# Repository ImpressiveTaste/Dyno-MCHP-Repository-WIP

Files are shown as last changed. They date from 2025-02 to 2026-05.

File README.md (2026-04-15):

# MC-Dyno: Motor Control Dynamometer  

<p align="center">
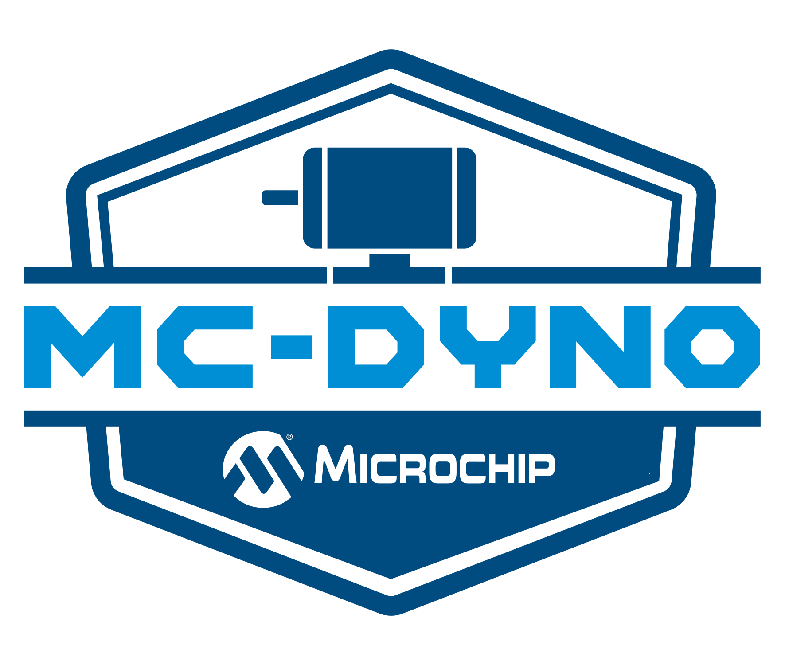
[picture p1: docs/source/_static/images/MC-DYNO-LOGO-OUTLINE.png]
MC-DYNO Logo
  
</p>

Last updated: December 2025

MC-Dyno is a compact, X2C-enabled motor dynamometer designed for load testing, algorithm validation, sensorless control development, and AI/ML data capture.  
This repository documents the setup, firmware workflow, load profiles, and usage instructions for running the MC-Dyno on Microchip motor-control platforms.

Documentation website (HTML build): [https://impressivetaste.github.io/Dyno-MCHP-Repository-WIP/](https://impressivetaste.github.io/Dyno-MCHP-Repository-WIP/)

The system supports both standalone operation (HEX-only, no toolchain required) and full SCILAB/X2C model-based workflow that allows to set torque and behaviour directly clicking on the model designed through model based design.  

It is compatible with the following hardware platforms:

- [MCLV-2](https://www.microchip.com/en-us/development-tool/dm330021-2)  
- [MCLV-48V-300W](https://www.microchip.com/en-us/development-tool/ev18h47a)  
- [MCHV-3](https://www.microchip.com/en-us/development-tool/dm330023-3)  
- [MCHV-230V-1.5kW](https://www.microchip.com/en-us/development-tool/ev78u65a)
---

<p align="center">
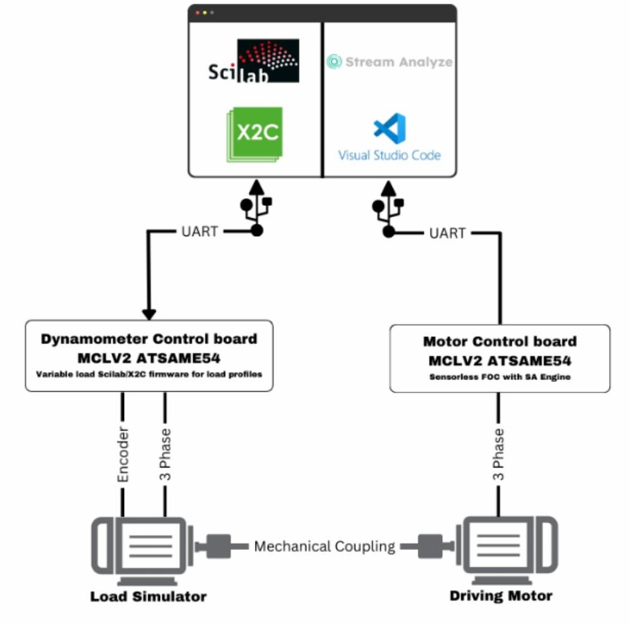
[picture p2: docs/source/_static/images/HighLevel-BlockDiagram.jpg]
High-Level-Block-Diagram
  
</p>

## What MC-Dyno Is

A ready-to-use motor dyno environment supporting:

- 4Q operation (CW/CCW, motor/generator/brake)
- Programmable load profiles (constant, trapezoid, sine, fan, angle-dependent, table-driven)
- Motor torque/speed profiles for DUT evaluation
- AI/ML dataset creation (anomalies, noise patterns, dynamic behaviours)
- Real-time monitoring via X2C Scope
- Standalone operation without Scilab/X2C if desired

The goal is to allow anyone to test motor algorithms quickly, without building or buying a custom, often expensive, setup.

## Key Features

### DYNO Mode
- Constant load (potentiometer or numeric)  
- Trapezoidal load (frequency, high/low values, ramp rates)  
- Fan load (k · n²)  
- Sine load (frequency, amplitude, offset)  
- Angle-dependent loads (electrical / mechanical)  
- Table-driven load profiles:
  - Unbalanced load (constant + sine)
  - Broken bearing (constant + rectangle)
  - Triangle (constant + triangle)
- Compressor-like load profiles (supported via table definition)

### Motor Mode
- Constant torque  
- Constant speed  
- Potentiometer or variable setpoints  
- Trapezoidal speed profiles  

### Hardware Highlights
- MCLV-2 motor control board  
- ATSAME54 PIM  
- Hurst 300 motor with encoder  
- RS232 connection (X2C Scope compatible)
- Optional Magtrol TS105/011 torque sensor  
- 3D-printable universal bracket (OpenSCAD)

## Repository Layout

```
miniDyno-2.0/
├── README.md <-- you are here
├── 3Dparts/ <-- OpenSCAD + STL universal motor bracket
├── MCDyno/
│ ├── mc_foc_dyno_same54_mclv2/
│ │ └── doc/ <-- project docs + standalone assets
│ └── ...
├── docs/ <-- rendered docs + static assets
└── ...
```

## Project Naming Conventions

Project names use underscore-separated "placeholder" in a fixed order:
`<topic>_<algorithm>_<S/SL>_<datatype>_<device>_<feature>_<demo-board>_<customer>`

The projects only keeps the "placeholders" that apply.

"placeholder" options (from the motor control naming list):
- topic (project area): MC, BLINKY, PWR, SENS
- algorithm (control/app type): FOC, BLOCK, MB, H3, QSPIN, LEG
- S/SL (variant tag): S, SL, SSL, DYNO, ZSMT, ZSMTLF
- datatype (numeric format): FIP, FLOAT, DOUBLE, FIP32
- device (target MCU): dsPIC33CK, dSPIC33EP, dSPIC33A, SAME54, SAME70, dsPIC33CKMC, dsPIC33CD, SAMC21, SAMD21
- feature (optional flag): PLL, SMO, PFC
- demo board (target board): MCLV2, MCHV2, MCHV3, MCLV48V300W, MCHV230VAC1.5KW, LVMC
- customer (optional tag): SA

"Placeholder" meanings and links:
- topic: MC = Motor Control; BLINKY = easy blinky example; PWR = Digital Power; SENS = sensing demonstration.
- algorithm: FOC = Field Oriented Control; BLOCK = Block commutation (six-step commutation); MB = motorBench-generated code; H3 = MPLAB Harmony 3 generated code; QSPIN = MPLAB Harmony QuickSpin generated code; LEG = Legacy (hand-authored) code.
- S/SL: S = sensored; SL = sensorless; SSL = sensorless single-shunt; DYNO = dynamometer (dyno) project; ZSMT = Zero-Speed/Maximum-Torque (ZS/MT) algorithm ([Microchip ZSMT overview](https://www.microchip.com/en-us/tools-resources/configure/mplab-harmony/quickspin/zsmt-algorithm)); ZSMTLF = ZS/MT low-frequency variant.
- datatype: FIP = fixed-point (usually 16-bit); FIP32 = 32-bit fixed-point; FLOAT = floating-point; DOUBLE = double-precision floating-point.
- feature: PLL = Phase-Locked Loop ([AN1292](https://ww1.microchip.com/downloads/en/AppNotes/01292A.pdf)); SMO = Sliding Mode Observer ([AN4398](https://ww1.microchip.com/downloads/aemDocuments/documents/MCU32/ApplicationNotes/ApplicationNotes/Sensorless-Field-Oriented-Control-for-a-Permanent-Magnet-Synchrono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)); PFC = Power Factor Correction([AN1208](https://ww1.microchip.com/downloads/en/appnotes/01208a.pdf)).
- demo board: [MCLV2](https://www.microchip.com/en-us/development-tool/dm330021-2), [MCHV2](https://www.microchip.com/en-us/tools-resources/reference-designs/aircon-board), [MCHV3](https://www.microchip.com/en-us/development-tool/dm330023-3), [MCLV48V300W](https://www.microchip.com/en-us/development-tool/ev18h47a), [MCHV230VAC1.5KW](https://www.microchip.com/en-us/development-tool/ev78u65a), [LVMC](https://www.microchip.com/en-us/solutions/technologies/motor-control-and-drive/hardware-development-tools).
- Partner: SA = Stream Analyze (AI/data collection)([Documentation](https://studio.streamanalyze.com/docs/guides/general-guides/intro)).

Examples:
- `mc_foc_dyno_same54_mclv2` (MC + FOC + DYNO + SAME54 + MCLV2)
- `mc_mb_sl_fip_dsPIC33CK_mclv48v300w.X` (MC + MB + SL + FIP + dsPIC33CK + MCLV48V300W)
- `MC_FOC_DYNO_SAME54_MCLV2.X.production.hex` (same fields, exported artifact)

## Requirements

### Hardware
- MCLV-2 development board  
- ATSAME54 PIM  
- Hurst 300 motor (with QEI encoder)  
- RS232 cable (DYNO ↔ Motor board)  
- Optional: Magtrol torque sensor  

### Jumpers
- JP1, JP2, JP3 → Current sense  
- JP4, JP5 → UART  
- Motor phases:
  - M1 = red
  - M2 = white
  - M3 = black
- Encoder:
  - HA = QEI white
  - HB = QEI blue

**Important:**  
Ensure the DYNO board power is physically connected to the motor board.  
Generator mode requires a valid power path to dissipate energy.

## Standalone Usage (No Scilab / No X2C)

### What you need
- Microchip programmer (ICD4, PICkit4, SNAP)
- MPLAB X or IPE

### Steps
1. Navigate to `MCDyno/mc_foc_dyno_same54_mclv2/doc/standalone` in the Github project.
2. Program the file:  
   **MC_FOC_DYNO_SAME54_MCLV2.X.production.hex**
3. Disconnect programmer and reset the MCLV-2.
4. Run **start.bat**.
5. In the GUI:
   - Select your COM port  
   - Press **Connect**  
   - Switch to the **Model** tab  

You're now running MC-Dyno in standalone mode.

Optional IGaT display (EV14C17A): program the display HEX separately from
`MCDyno/igat_ev14c17a/doc/standalone/`.

Motor-side DIM firmware (MCLV-48V-300W): program one of the DIM HEX files from
`motor_ACT57BLF02/mclv48v300w_dim_hex/doc/standalone/` to showcase different
algorithms (Single-Shunt, ZS/MT, or X2C-enabled).

## Using miniDyno with SCILAB + X2C

### Requirements
- Scilab 6.1.1  
- X2C 6.4  
- MPLAB X (Harmony 3 + XC32 free compiler)  
- Microchip programmer  

This mode allows you to modify model parameters, load tables, and control algorithms using X2C’s model-based workflow.

## DYNO Torque Profiles

### torque_mode
- 0 = Constant (potentiometer)
- 1 = Constant (const_torque)
- 2 = Trapezoid (freq, high, low, Tr, Tf)
- 3 = Fan load (fan_gain)
- 4 = Sine (A, f, fmax, Offset)
- 5 = Unbalanced (GainT5, ConstT5)
- 6 = Broken bearing (GainT6, ConstT6)
- 7 = Triangle (GainT7, ConstT7)

## Motor Mode Parameters

#### speed_mode
- 0 = Constant speed (potentiometer)
- 1 = Constant speed (const_speed)
- 2 = Trapezoidal speed profile

### Additional controls:

#### motor_torquemode
- 1 = speed control
- 0 = torque control

#### DynoMotor
- 1 = Dyno mode
- 0 = Motor mode

## X2C Scope

1. Start X2C Scope  
2. Select COM port  
3. Set Sample Time Factor  
4. Press **Sample**  

Signals stream in real time for debugging load/torque profiles, speed control, angle behaviour, and anomalies.

## 3D Printable Brackets

For making the MC-Dyno, there is a need of brakets to fix the motors, and allow for the connection between the rotor shafts guaranteeing alignment. To do so, in the location: `3Dparts` of this repository, both STL and openSCAD 3D models are made avaialble to allow to use standard brakets for some specific motors. 

If you are using a different motor, you can use the [openSCAD](https://openscad.org) files to create your own motor braket parametrically. If you make a new motor, feel free to share in this repository. 

Printing recommendations in a standard FDM printer:
- PLA or PETG (PETG preferrable)  
- 0.2 mm layer height  
- 100% infill  

## Future Enhancements

- Position control for ZSMT tuning  
- Standalone GUI  
- Torque sensor calibration  
- Real torque control mode  
- Power measurement (in/out)  
- MCHV-2/3 support  
- MCLV-48V-300W port  

## Want to contribute?
This project is open source and contributions are welcome. 
If you are new to GitHub, Github pages, and so on... don't worry, here is a small video that tries to explain how to get a setup for contributions ready: https://youtu.be/irQH9ktzQAw

## Official Logos

The MC-Dyno logos are available for use in documentation, presentations, and related projects. The following variants are provided:

| Logo | File | Best for |
|---|---|---|
|  | `MC-DYNO-LOGO-OUTLINE.png` | Light backgrounds |
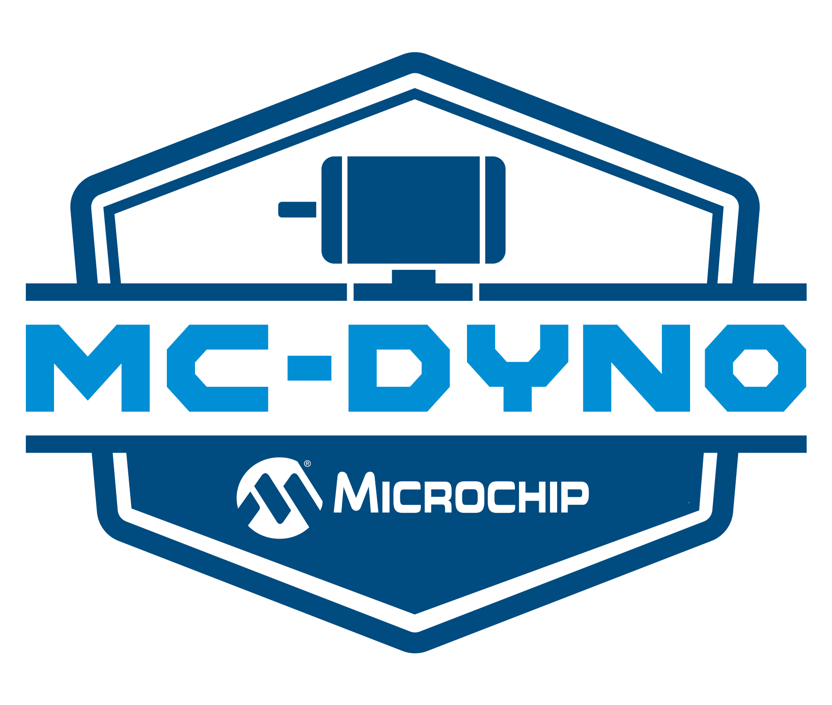
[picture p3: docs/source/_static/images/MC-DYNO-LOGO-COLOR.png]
|  | `MC-DYNO-LOGO-COLOR.png` | General use |
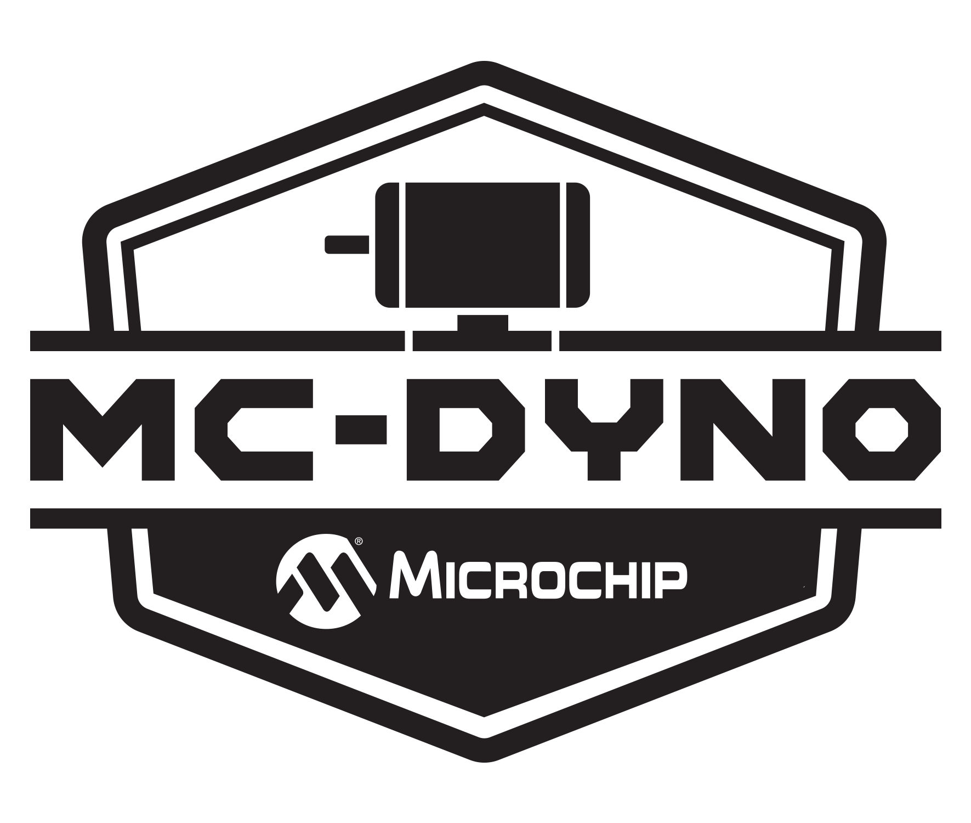
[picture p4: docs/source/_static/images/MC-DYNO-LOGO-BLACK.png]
|  | `MC-DYNO-LOGO-BLACK.png` | Print / monochrome |
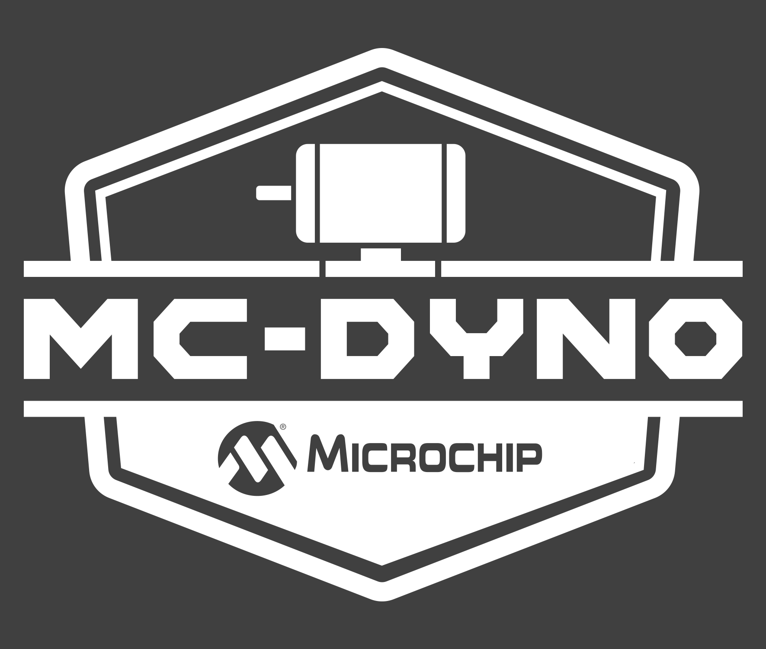
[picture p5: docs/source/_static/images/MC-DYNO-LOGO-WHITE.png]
|  | `MC-DYNO-LOGO-WHITE.png` | Dark backgrounds |

All logos are located in `docs/source/_static/images/`.

----------------------------------------------------------------------
REFERENCE & DISCLAIMER
----------------------------------------------------------------------

This project, including all hardware designs, documentation, images, and configuration examples, is provided for reference and evaluation purposes only.

It is supplied “AS IS”, without any express, implied, or statutory warranties, including but not limited to warranties of merchantability, fitness for a particular purpose, or non-infringement. The information is intended to assist with experimentation, learning, and prototyping and does not constitute a certified or production-ready design.

The author assumes no responsibility or liability for any errors, omissions, hardware damage, data loss, personal injury, or other consequences arising from the use, reproduction, modification, or deployment of this material. Users are solely responsible for verifying correctness, safety, electrical compliance, and suitability for their specific application

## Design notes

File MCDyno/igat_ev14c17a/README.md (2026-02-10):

# IGaT Display (EV14C17A) Firmware

This folder is for the Integrated Graphics and Touch (IGaT) Curiosity Evaluation Kit
(EV14C17A) display firmware used alongside the Dyno. The IGaT board is separate
hardware from the dyno controller and is programmed independently.

The IGaT display HEX file is in "MCDyno/igat_ev14c17a/doc/standalone/ATSAME51J20A_MC_Dyno_08_01_2026_IGAT.hex"

Currently the IGAT is only used as a display, but feel free to modify the code, such to be able to use it as a controller for the Dyno or motor.

## Programming (Standalone)

1. Connect directly with a microUSB cable to the debug port of the EV14C17A board.
2. In MPLAB IPE, select the ATSAME51PJ20A device on the kit.
3. Program the HEX from `doc/standalone/`.
4. Reset the board to run the UI.

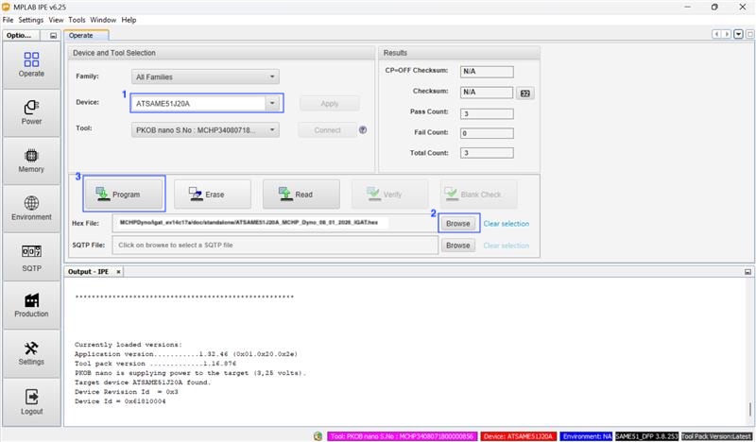
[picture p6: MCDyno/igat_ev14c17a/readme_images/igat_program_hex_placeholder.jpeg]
Programming the IGaT HEX


## Final Result

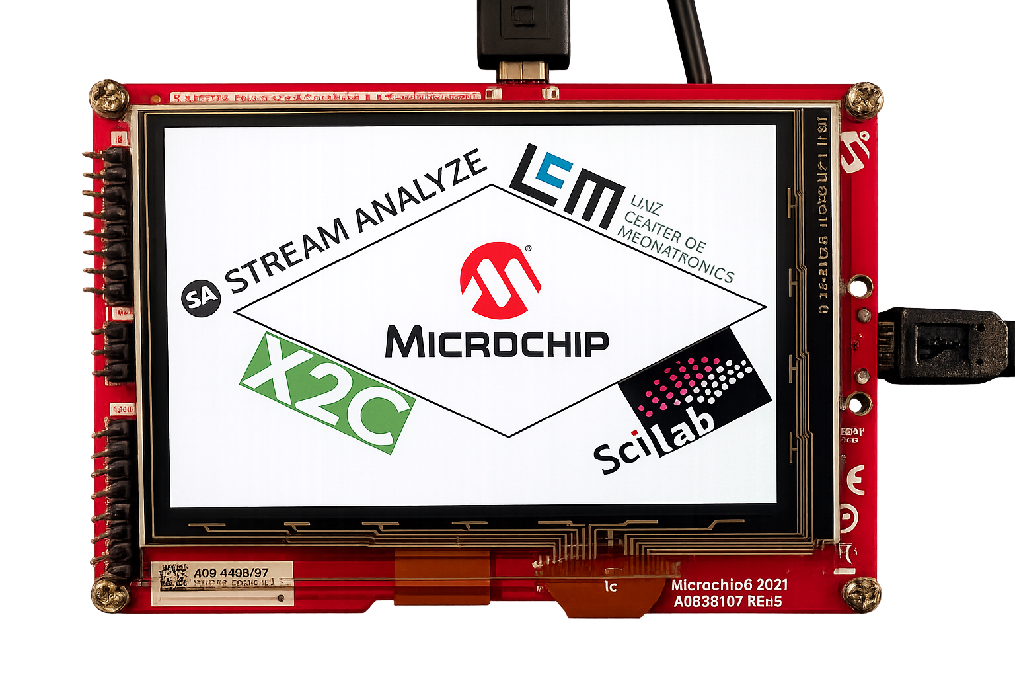
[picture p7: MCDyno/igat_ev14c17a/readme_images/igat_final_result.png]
IGaT display final result


The logos represent the different tools used for making the MC-Dyno. 

More info on the kit: https://www.microchip.com/en-us/development-tool/ev14c17a

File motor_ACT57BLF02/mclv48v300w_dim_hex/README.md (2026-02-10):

# MCLV-48V-300W Motor DIM HEX Files

These HEX files are for the motor-side control DIM plugged into the
MCLV-48V-300W Development Board (EV18H47A). Use them to showcase different
control algorithms on the dyno.

Example DIM: dsPIC33CK256MP508 Motor Control DIM (EV62P66A)
https://www.microchip.com/en-us/development-tool/ev62p66a

HEX location:

`doc/standalone/`

## Included Firmware

- `dsPIC33AK128MC106_MC_Dyno_08_01_2026_SingleShunt_DIM.hex`
  - Target DIM: dsPIC33AK128MC106.
  - MCAF R8 single-shunt current measurement demo.
  - Uses DC-link shunt reconstruction with two samples per PWM period.
  - Requires a dedicated, high-priority ADC ISR that triggers twice per PWM
    cycle and a minimum switching-state window (t_sample + dead time).
  - For estimators other than ZS/MT, use single update in Dual Edge Center
    Aligned PWM mode.

- `dsPIC33CK256MP508_MC_Dyno_08_01_2026_ZSMT_DIM.hex`
  - Target DIM: dsPIC33CK256MP508.
  - Zero-Speed / Maximum Torque (ZS/MT) Estimator
  - ZS/MT is a sensorless position and speed estimation algorithm specifically
    designed to operate where back-EMF based estimators fail, at zero and
    ultra-low speeds.
  - Operating Principle - High-Frequency Signal Injection:
    ZS/MT injects a high-frequency excitation voltage into the stator and
    measures the motor response to determine rotor angle at standstill.
  - Motor Requirements (Saliency):
    Requires significant Ld != Lq saliency, intended for IPMSM machines.
  - Startup Sequence - IPC for Zero-Speed Torque Production:
    Uses "ZS/MT + Initial Position Correction (IPC)" to align the stator field
    before motion begins.
  - Hybrid Operation - Low-Speed to High-Speed Transition:
    Uses ZS/MT at low speed and a back-EMF estimator (for example, PLL) at
    higher speed due to voltage headroom limits.
  - Tuning and Configuration Parameters

- `dsPIC33CK256MP508_MC_Dyno_08_01_2026_X2C_DIM.hex`
  - Target DIM: dsPIC33CK256MP508.
  - X2C-enabled variant for real-time monitoring and tuning.

## Programming (Standalone)

1. Insert the motor control DIM into the MCLV-48V-300W board.
2. Connect a programmer (ICD4, PICkit 4, SNAP).
3. In MPLAB IPE or MPLAB X, select the DIM device and program the HEX from
   `doc/standalone/`.
4. Reset the board.

Reference hardware:
https://www.microchip.com/en-us/development-tool/ev18h47a

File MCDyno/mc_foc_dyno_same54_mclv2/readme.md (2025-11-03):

# MPLAB X Project: MC_FOC_DYNO_SAME54_MCLV2

This is a dynamometer control demo project for [MCLV2 board](https://www.microchip.com/developmenttools/ProductDetails/dm330021-2) development board and [SAME54](https://www.microchip.com/DevelopmentTools/ProductDetails/PartNO/MA320207) microcontroller.

Apply dynamic load to test motor control development.

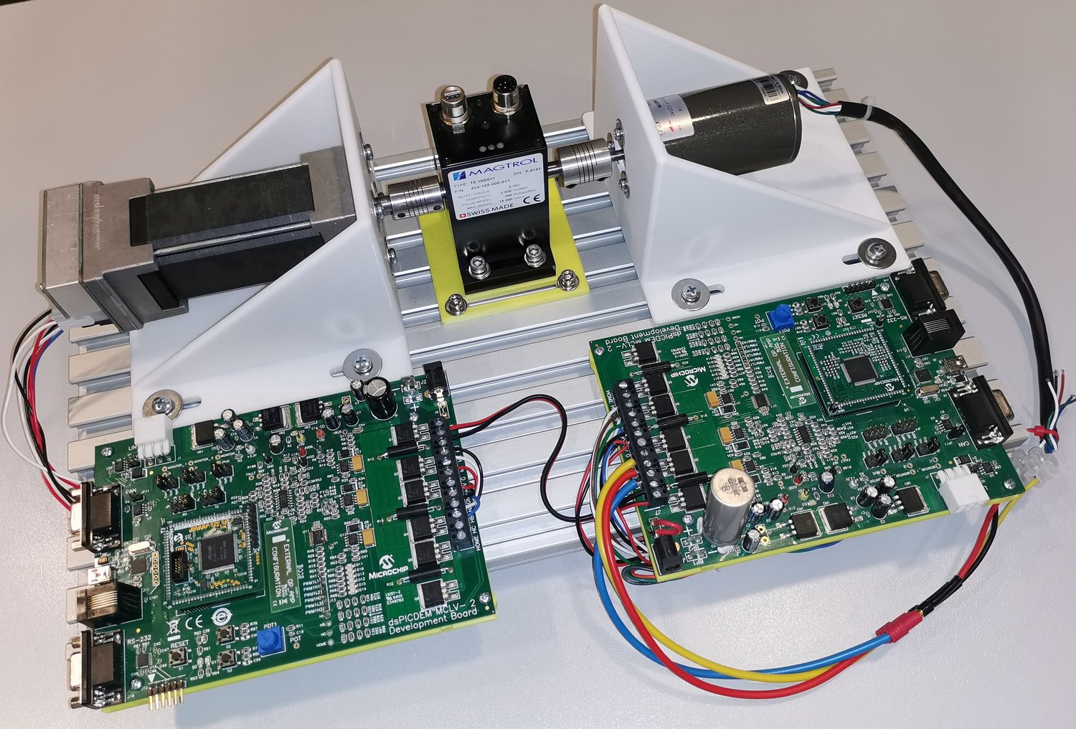
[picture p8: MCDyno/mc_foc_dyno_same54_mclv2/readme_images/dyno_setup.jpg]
Overview

### Features
* Running standalone without scilab (No SCILAB, X2C and XC32 compiler required)
* Run-time [monitoring](#monitoring-signals) (virtual scope)
* Change load profiles in run-time
  * Constant load from potentiometer
  * Constant load from variable
  * Trapezoidal load (variables: frequency, raising/falling ramp, high/low value)
  * Fan load (k*n²[rpm], variable:k 
  * Sine load ( variable: frequency, amplitude, offset)
  * Angle dependent loads ( electrical/mechanical)
    * 3 different table dependent load profiles (variables: amplitude and offset)
      * Unbalanced load (constant + sine)
      * Broken bearing (constant + rectangle)
      * Triangle ( constant + triangle)
    * Various compressor load profiles possible

## Getting Started

The demo is ready to use with the [listed hardwares below](#hardware).

1. Clone or Download project to mc_foc_sl_fip_dspic33ck_lvmc.x folder. (Keep the folder name)
2. [Connect Hardware](#connectors-used)
3. Move to [..\mc_foc_dyno_same54_mclv2\doc\standalone]
4. Program [MC_FOC_DYNO_SAME54_MCLV2.X.production.hex] onto your SAME54 PIM
5. Disconnect the programmer and reset the MCLV-2 board
6. Execute start.bat 

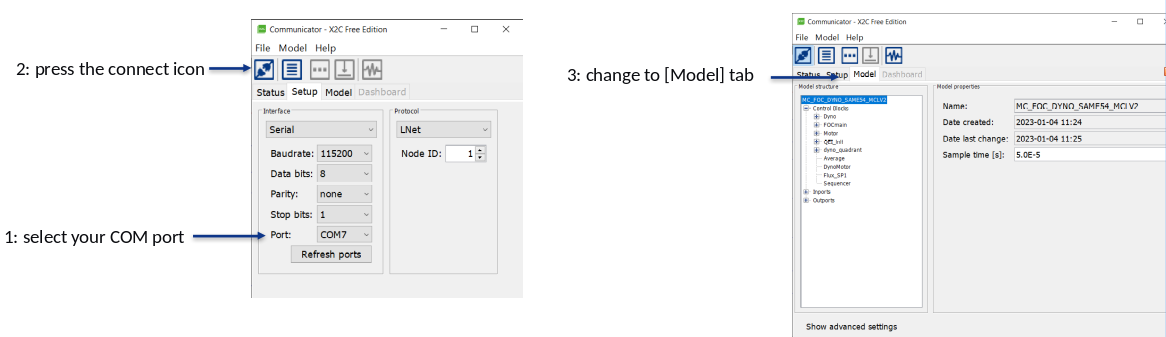
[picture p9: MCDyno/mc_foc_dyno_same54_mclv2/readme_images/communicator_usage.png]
communicator


## HW setup

* MCLV-2
* ATSAME54
* Hurst300 motor with encoder
* RS232 cable
* Software setup
* Microchip programmer (SW and HW)
* MCLV-2 Settings
  * JP1,2,3 -> Curr
  * JP4,5 -> UART
  * M1 – red
  * M2 – white
  * M3 – black
  * HA – QEI white
  * HB – QEI blue

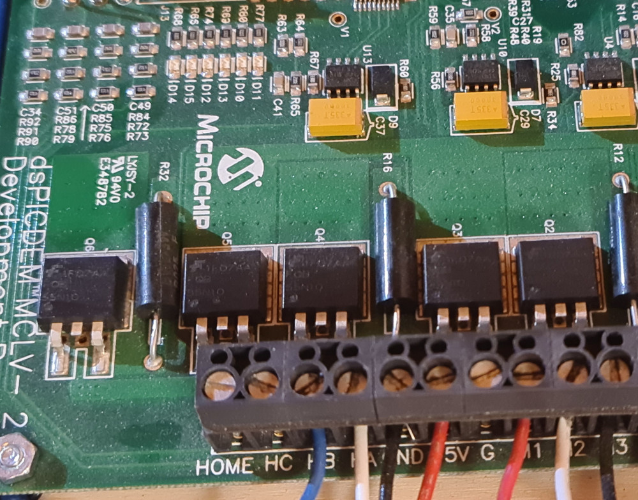
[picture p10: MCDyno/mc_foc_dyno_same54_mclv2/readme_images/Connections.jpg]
HW setup


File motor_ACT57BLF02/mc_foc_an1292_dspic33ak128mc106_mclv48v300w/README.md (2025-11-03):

 
## Sensorless FOC using PLL Estimator for PMSM : MCLV-48V-300W and dsPIC33AK128MC106 Motor Control DIM

## 1. INTRODUCTION
This document describes the setup requirements for driving a Permanent Magnet Synchronous Motor (PMSM) using Sensorless Field Oriented Control (FOC) and PLL Estimator Algorithm on the hardware platform [EV18H47A](https://www.microchip.com/en-us/development-tool/ev18h47a) "MCLV-48V-300W Development Board"  and [EV68M17A](https://www.microchip.com/en-us/development-tool/ev68m17a) "dsPIC33AK128MC106 Motor Control Dual In-line Module (DIM)".

For details about PLL estimator, refer to Microchip application note [AN1292](https://ww1.microchip.com/downloads/aemDocuments/documents/OTH/ApplicationNotes/ApplicationNotes/01292A.pdf) “Sensorless Field Oriented Control (FOC) for a Permanent Magnet Synchronous Motor (PMSM) Using a PLL Estimator and Field Weakening (FW)”
</br>

## 2. SUGGESTED DEMONSTRATION REQUIREMENTS

### 2.1 Motor Control Application Firmware Required for the Demonstration

To clone or download this application firmware on GitHub, 
- Navigate to the [main page of this repository](https://github.com/microchip-pic-avr-solutions/mclv48v300w-33ak128mc106-pmsm-an1292-foc-pll) and 
- On the tab **<> Code**, above the list of files in the right-hand corner, click Code, then from the menu, click **Download ZIP** or copy the repository URL to **clone.**
> **Note:** </br>
>In this document, hereinafter this firmware package is referred as **firmware.**
### 2.2 Software Tools Used for Testing the firmware

- MPLAB® X IDE **v6.20** 
- Device Family Pack (DFP): **dsPIC33AK-MC_DFP v1.0.33**
- Curiosity/Starter Kits Tool Pack : **PKOB4_TP v1.14.1168**
- MPLAB® XC-DSC Compiler **v3.10**
- MPLAB® X IDE Plugin: **X2C-Scope v1.6.6** 
> **Note:** </br>
>The software used for testing the firmware prior to release is listed above. It is recommended to use these or later versions of the tool for building the firmware. All previous versions of Device Family Packs (DFP) and Tool Packs can be downloaded from [Microchip Packs Repository.](https://packs.download.microchip.com/)
### 2.3 Hardware Tools Required for the Demonstration
- MCLV-48V-300W Development Board [(EV18H47A)](https://www.microchip.com/en-us/development-tool/ev18h47a)
- dsPIC33AK128MC106 Motor Control Dual In-line Module [(EV68M17A)](https://www.microchip.com/en-us/development-tool/ev68m17a)
- 24V Power Supply [(AC002013)](https://www.microchipdirect.com/dev-tools/AC002013)
- 24V 3-Phase Brushless DC Motor - Hurst DMA0204024B101 [(AC300022)](https://www.microchip.com/en-us/development-tool/AC300022) or,
- 24V 3-Phase Brushless DC Motor - Hurst DMB0224C10002 [(AC300020)](https://www.microchip.com/en-us/development-tool/AC300020)

> **Note:** </br>
> All items listed under the section Hardware Tools Required for the Demonstration are available at [microchip DIRECT](https://www.microchipdirect.com/) 
>- Hurst DMA0204024B101(AC300022) is referred as Hurst300 or Long Hurst in the firmware
>- Hurst DMB0224C10002(AC300020) is referred as Hurst075 or Short Hurst in the firmware
</br>

## 3. HARDWARE SETUP
This section describes the hardware setup required for the demonstration.
> **Note:** </br>
>In this document, hereinafter the MCLV-48V-300W Development Board is referred as **development board**.

1. Motor currents are amplified on the MCLV-48V-300W development board; it can also be amplified by the amplifiers internal to the dsPIC33AK128MC106 on the DIM. The firmware and DIM are configured to sample and convert internal amplifier outputs (**'internal op-amp configuration'**) by default to measure the motor currents needed to implement FOC. **Table-1** summarizes the resistors to be populated and removed to convert the DIM from **‘internal op-amp configuration’** to **‘external op-amp configuration’** or vice versa.

     <p align="left" >
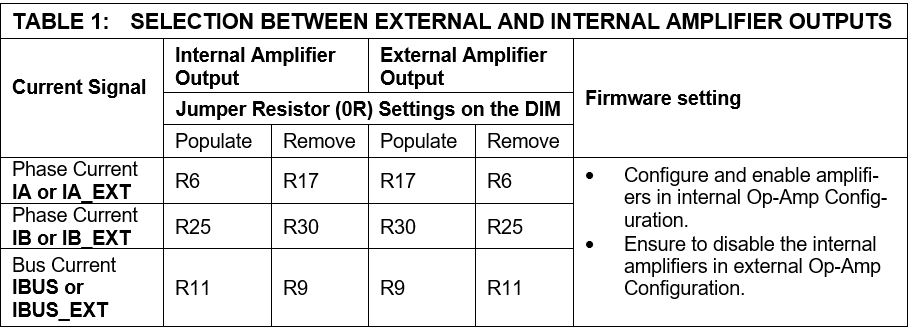
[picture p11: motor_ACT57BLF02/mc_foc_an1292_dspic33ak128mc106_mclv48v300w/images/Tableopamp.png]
     </p>

2. Insert the **dsPIC33AK128MC106 Motor Control DIM** into the DIM Interface **connector J8** on the development board. Make sure the DIM is placed correctly and oriented before going ahead.

     <p align="left" >
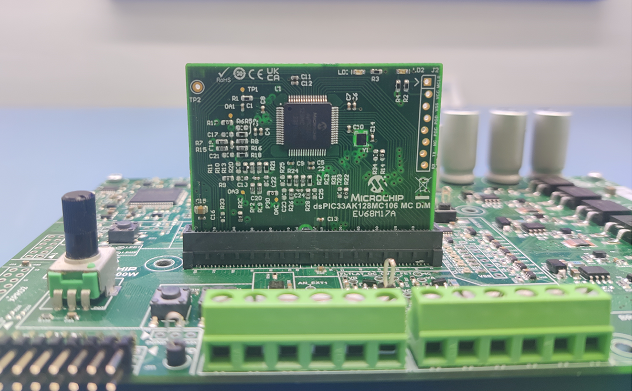
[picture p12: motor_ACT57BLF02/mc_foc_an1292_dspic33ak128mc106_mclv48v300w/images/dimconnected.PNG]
     </p>

3. Connect the 3-phase wires from the motor to PHC, PHB, and PHA of the **connector J4**(no specific order), provided on the development board.

     <p align="left" >
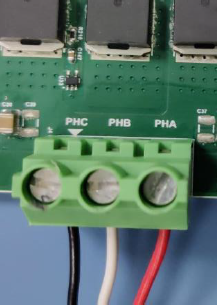
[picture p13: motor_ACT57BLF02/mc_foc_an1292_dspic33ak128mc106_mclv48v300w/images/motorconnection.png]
      </p>

4. Plug the 24V power supply to **connector J1** on the development board. Alternatively, the development board can also be powered through connector J3.
      <p align="left">
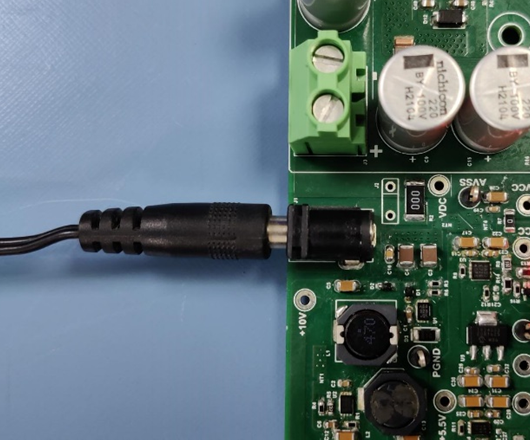
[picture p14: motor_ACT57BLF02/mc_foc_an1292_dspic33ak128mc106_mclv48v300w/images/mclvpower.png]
      </p>

 5. The board has an onboard programmer **PICkit™ On Board (PKoBv4)** , which can be used for programming or debugging the microcontroller or dsPIC DSC on the DIM. To use the onboard programmer, connect a micro-USB cable between the Host PC and **connector J16** on the development board.
      <p align="left">
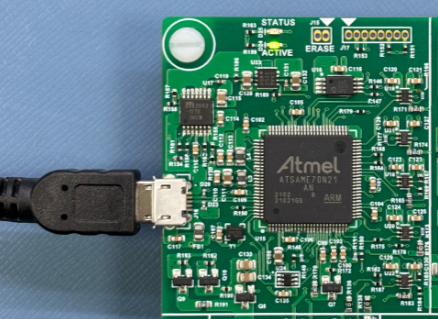
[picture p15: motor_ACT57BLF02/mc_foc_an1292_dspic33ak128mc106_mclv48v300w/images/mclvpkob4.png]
     </p>

 6. Alternatively, connect the Microchip programmer/debugger MPLAB® PICkit™ 4 In-Circuit Debugger[(PG164140)](https://www.microchip.com/en-us/development-tool/pg164140) between the Host PC used for programming the device and the **ICSP header J9** on the development board (as shown). Ensure that PICkit 4 is oriented correctly before proceeding.
      <p align="left">
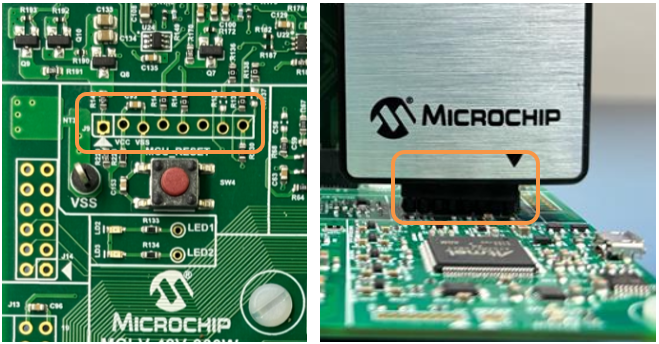
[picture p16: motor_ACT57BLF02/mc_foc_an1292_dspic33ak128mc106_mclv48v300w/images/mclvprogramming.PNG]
       </p>
 </br>

## 4. SOFTWARE SETUP AND RUN
### 4.1 Setup: MPLAB X IDE and MPLAB XC-DSC Compiler
Install **MPLAB X IDE** and **MPLAB XC-DSC Compiler** versions that support the device **dsPIC33AK128MC106** and **PKoBv4.** The MPLAB X IDE, MPLAB XC-DSC Compiler, and X2C-Scope plug-in used for testing the firmware are mentioned in the [Motor Control Application Firmware Required for the Demonstration](#21-motor-control-application-firmware-required-for-the-demonstration) section. 

To get help on  

- MPLAB X IDE installation, refer [link](https://microchipdeveloper.com/mplabx:installation)
- MPLAB XC-DSC Compiler installation steps, refer [link](https://developerhelp.microchip.com/xwiki/bin/view/software-tools/xc-dsc/install/)

If MPLAB IDE v8 or earlier is already installed on your computer, then run the MPLAB driver switcher (Installed when MPLAB®X IDE is installed) to switch from MPLAB IDE v8 drivers to MPLAB X IDE drivers. If you have Windows 8 or 10, you must run the MPLAB driver switcher in **Administrator Mode**. To run the Device Driver Switcher GUI application as administrator, right-click on the executable (or desktop icon) and select **Run as Administrator**. For more details, refer to the MPLAB X IDE help topic **“Before You Begin: Install the USB Device Drivers (For Hardware Tools): USB Driver Installation for Windows Operating Systems.”**

### 4.2 Setup: X2C-SCOPE
X2C-Scope is a MPLAB X IDE plugin that allows developers to interact with an application while it runs. X2C-Scope enables you to read, write, and plot global variables (for motor control) in real-time. It communicates with the target using the UART. To use X2C-Scope, the plugin must be installed. To set up and use X2C-Scope, refer to the instructions provided on the [web page](https://x2cscope.github.io/docs/MPLABX_Plugin.html).

## 5.  BASIC DEMONSTRATION
### 5.1 Firmware Description
The firmware version needed for the demonstration is mentioned in the section [Motor Control Application Firmware Required for the Demonstration](#21-motor-control-application-firmware-required-for-the-demonstration) section. This firmware is implemented to work on Microchip’s Digital signal controller (dsPIC® DSC) **dsPIC33AK128MC106**. For more information, see the **dsPIC33AK128MC106 Family datasheet [(DS70005539)](https://ww1.microchip.com/downloads/aemDocuments/documents/MCU16/ProductDocuments/DataSheets/dsPIC33AK128MC106-Family-Data-Sheet-DS70005539.pdf)**.

The Motor Control Demo application uses a push button to start or stop the motor and a potentiometer to vary the speed of the motor. This Motor Control Demo Application configures and uses peripherals like PWM, ADC, UART, etc. For more details, refer to Microchip Application note **[AN1292](https://ww1.microchip.com/downloads/aemDocuments/documents/OTH/ApplicationNotes/ApplicationNotes/01292A.pdf), “Sensorless Field Oriented Control (FOC) for a Permanent Magnet Synchronous Motor (PMSM) Using a PLL Estimator and Field Weakening (FW)”** available on the [Microchip website](https://www.microchip.com/en-us/application-notes).

> **Note:**</br>
> The project may not build correctly in Windows OS if the Maximum path length of any source file in the project is more than 260 characters. In case the absolute path exceeds or nears the maximum length, do any (or both) of the following:
> - Shorten the directory name containing the firmware used in this demonstration. If you renamed the directory, consider the new name while reading the instructions provided in the upcoming sections of the document.
> - Place firmware in a location such that the total path length of each file included in the projects does not exceed the Maximum Path length specified. </br>
> Refer to MPLAB X IDE help topic **“Path, File, and Folder Name Restrictions”** for details. 

### 5.2 Basic Demonstration
Follow the below instructions, step by step, to set up and run the motor control demo application:

1. Start **MPLAB X IDE** and open the project **pmsm.X (File > Open Project)** with device selection **dsPIC33AK128MC106.**  
    <p align="left">
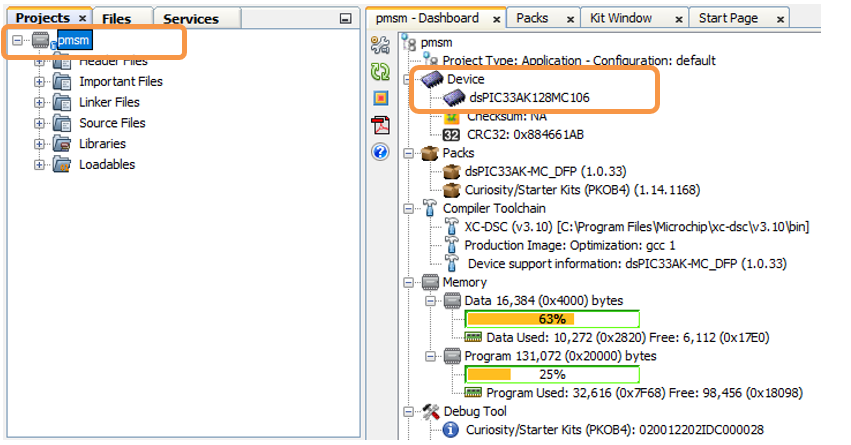
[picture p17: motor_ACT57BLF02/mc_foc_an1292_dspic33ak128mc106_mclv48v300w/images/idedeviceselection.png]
       </p>

2. Set the project **pmsm.X** as the main project by right-clicking on the project name and selecting **Set as Main Project** as shown. The project **pmsm.X** will then appear in **bold.**
    <p align="left">
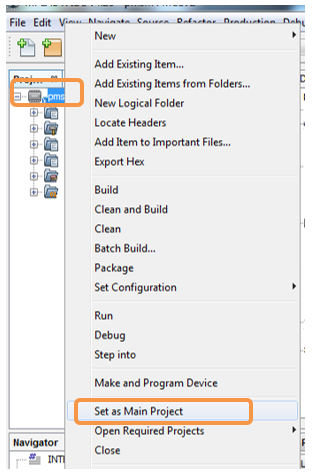
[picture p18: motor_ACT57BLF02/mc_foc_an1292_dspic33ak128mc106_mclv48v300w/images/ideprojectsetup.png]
     </p>

3. Open <code>**userparms.h** </code> (**pmsm.X > Header Files**) in the project **pmsm.X.**  
     - Ensure that the macros <code>**OPEN_LOOP_FUNCTIONING</code>, <code>TORQUE_MODE</code>, and <code>SINGLE_SHUNT</code>** is not defined in the header file<code> **userparms.h.**</code>
          
     - Firmware is configured to run with Hurst DMA0204024B101 Motor(Hurst300 or Long Hurst-[AC300022](https://www.microchip.com/en-us/development-tool/AC300022)) by default. To run with Hurst DMB0224C10002 Motor(Hurst075 or Short Hurst-[AC300020](https://www.microchip.com/en-us/development-tool/AC300020)), **define** the macro to **MOTOR 2** in <code>**userparms.h.**</code>
          
     - When internal amplifiers are used for current amplification (referred to as **internal op-amp configuration**), **define** the macro <code>**INTERNAL_OPAMP_CONFIG**</code> in <code>**userparms.h.**</code>
          
     - Otherwise, if external amplifiers are used for current amplification (referred to as **external op-amp configuration**), undefine the macro <code>**INTERNAL_OPAMP_CONFIG**</code> in the header file <code>**userparms.h.**</code>
         

> **Note:**</br>
>The motor phase currents can be reconstructed from the DC Bus current by appropriately sampling it during the PWM switching period, called as single-shunt reconstruction algorithm. The firmware can be configured to demonstrate **the single shunt reconstruction algorithm** by defining the macro <code>**SINGLE_SHUNT**</code> in the header file <code>**userparms.h**</code> 
>For additional information, refer to Microchip application note **[AN1299](http://ww1.microchip.com/downloads/en/appnotes/01299a.pdf), “Single-Shunt Three-Phase Current Reconstruction Algorithm for Sensorless FOC of a PMSM.”**
>By default, the firmware uses phase currents measured across the phase shunt resistors on two of the half-bridges of the three-phase inverter (**‘dual shunt configuration’**) to implement FOC.

4. Right-click on the project **pmsm.X** and select **Properties** to open its **Project Properties** Dialog. Click the **Conf:[default]** category to reveal the general project configuration information. The development tools used for testing the firmware are listed in section [2.2 Software Tools Used for Testing the firmware.](#22-software-tools-used-for-testing-the-firmware)

     In the **Conf:[default]** category window: 
     - Ensure the selected **Device** is **dsPIC33AK128MC106.**
     - Select the **Connected Hardware Tool** to be used for programming and debugging. 
     - Select the specific Device Family Pack (DFP) from the available list of **Packs.** In this case, **dsPIC33AK-MC_DFP 1.0.33** is selected. 
     - Select the specific **Compiler Toolchain** from the available list of **XC-DSC** compilers. 
     In this case, **XC-DSC(v3.10)** is selected.
     - After selecting Hardware Tool and Compiler Toolchain, Device Pack, click the button **Apply**

     Please ensure that the selected MPLAB® XC-DSC Compiler and Device Pack support the device configured in the firmware

     <p align="left">
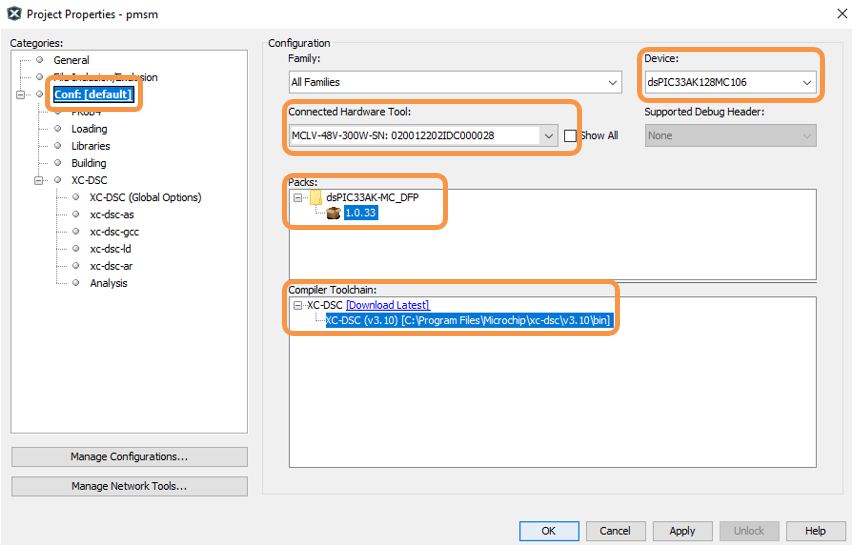
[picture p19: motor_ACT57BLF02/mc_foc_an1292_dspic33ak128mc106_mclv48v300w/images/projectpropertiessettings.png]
     </p>

5. Ensure that the checkbox **Load symbols when programming or building for production (slows process)** is checked under the **Loading** category of the **Project Properties** window.       
        
      <p align="left">
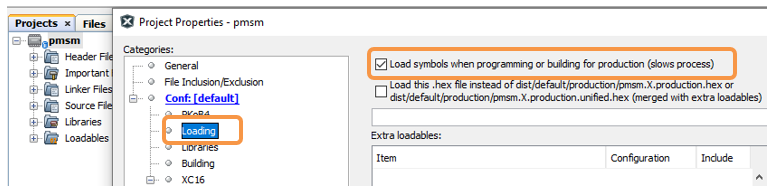
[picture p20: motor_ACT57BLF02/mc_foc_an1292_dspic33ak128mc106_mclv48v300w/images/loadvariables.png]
      </p>

     Also, go to **Tools > Options** , and
           
      <p align="left">
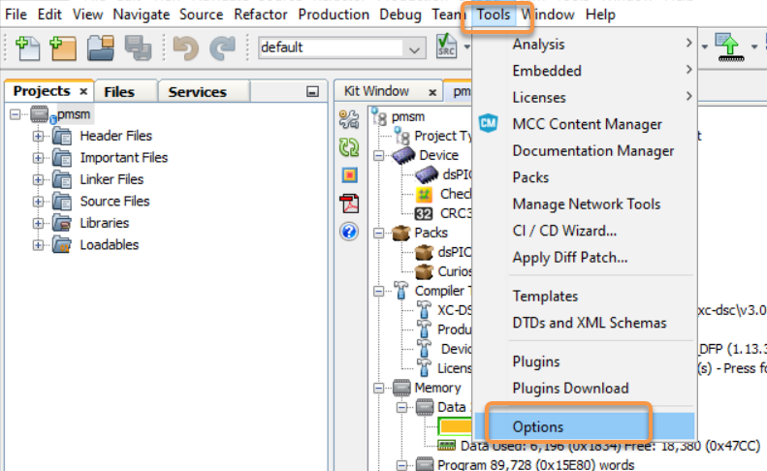
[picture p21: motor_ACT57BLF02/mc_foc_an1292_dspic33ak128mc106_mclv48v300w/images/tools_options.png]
      </p>
      
    Open the  **Embedded > Generic Settings** tab and ensure that the **ELF debug session symbol load methodology (MIPS/ARM)** is selected as **Pre-procesed (Legacy)** from the drop down.
           
      <p align="left">
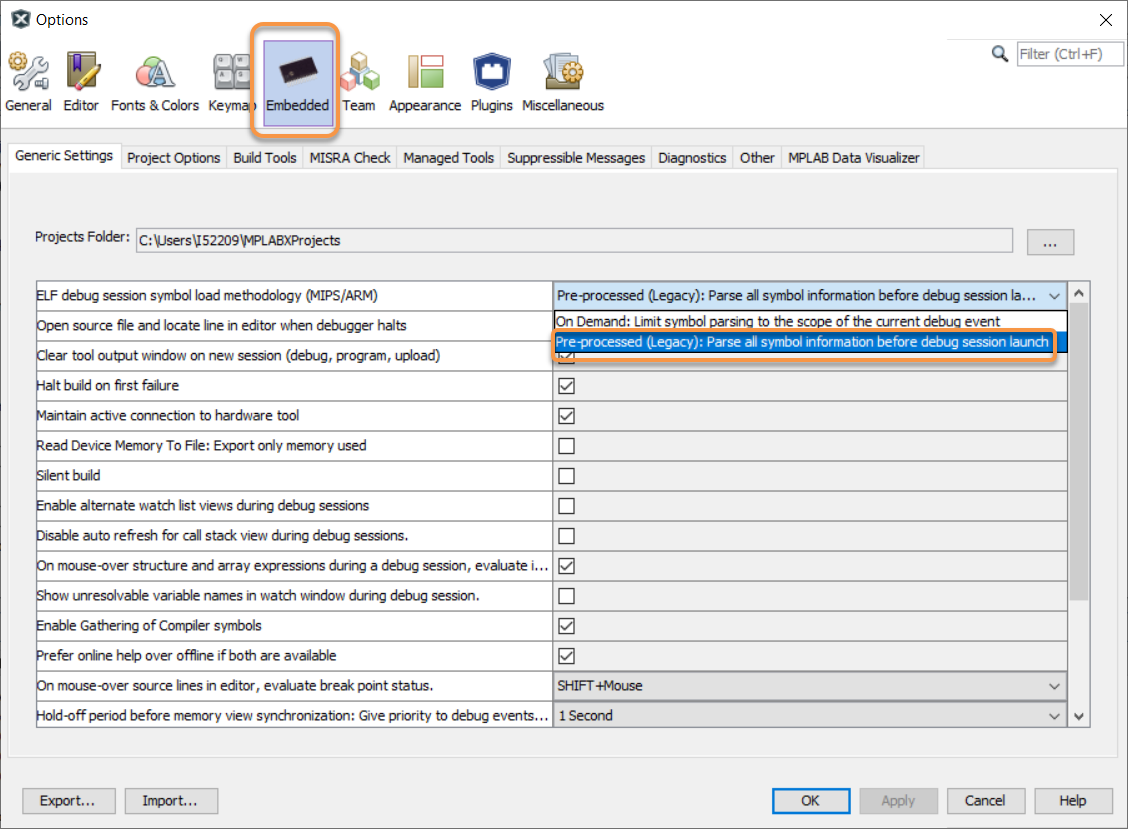
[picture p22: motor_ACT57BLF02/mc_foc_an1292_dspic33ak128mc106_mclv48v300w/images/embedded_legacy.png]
      </p>
6. To build the project (in this case, **pmsm.X**) and program the device dsPIC33AK128MC106, click **Make and Program Device Main project** on the toolbar
    <p align="left">
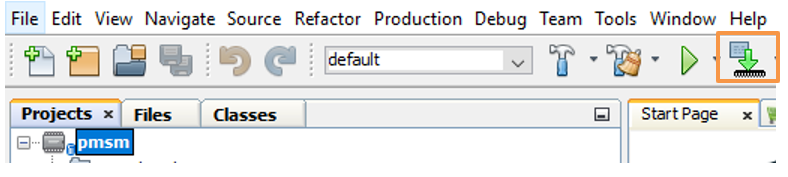
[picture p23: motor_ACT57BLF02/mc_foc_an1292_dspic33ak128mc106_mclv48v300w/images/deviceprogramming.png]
    </p>
  
7. If the device is successfully programmed, **LED1 (LD2)** will be **blinking**, indicating that the dsPIC® DSC is enabled.
    <p align="left">
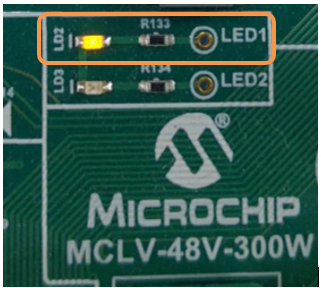
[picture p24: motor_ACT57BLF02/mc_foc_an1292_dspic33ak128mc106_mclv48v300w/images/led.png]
     </p>

8. Run or stop the motor by pressing the push button **SW1.** The motor should start spinning smoothly in one direction in the nominal speed range. Ensure that the motor is spinning smoothly without any vibration. The LED **LED2(LD3)** is turned **ON** to show the button is pressed to start the motor.
     <p align="left">
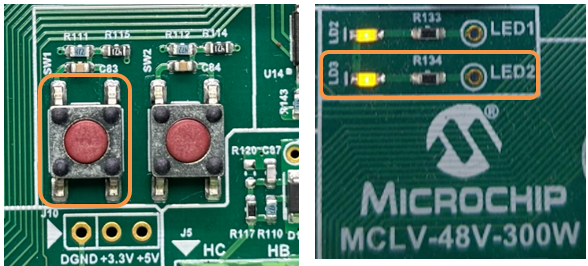
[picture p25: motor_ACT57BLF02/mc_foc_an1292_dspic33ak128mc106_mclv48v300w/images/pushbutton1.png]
     </p>

9. The motor speed can be varied using the potentiometer **(POT1).**
    <p align="left">
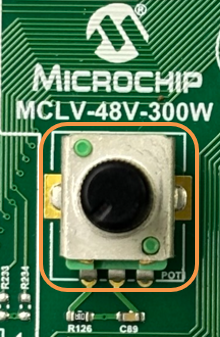
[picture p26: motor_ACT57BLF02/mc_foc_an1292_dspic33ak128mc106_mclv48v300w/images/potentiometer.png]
    </p>
 
10. Press the push button **SW2** to enter the extended speed range (<code>NOMINAL_SPEED_RPM</code> to <code>MAXIMUM_SPEED_RPM</code>).
Press the push button **SW2** again to revert the speed of the motor to its nominal speed range (<code>END_SPEED_RPM</code> to <code>NOMINAL_SPEED_RPM</code>).
     <p align="left">
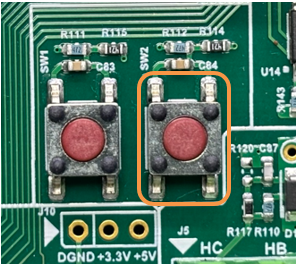
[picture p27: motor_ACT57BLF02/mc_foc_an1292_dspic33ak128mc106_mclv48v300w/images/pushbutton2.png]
     </p> 

11. Press the push button **SW1** to stop the motor.

>**Note:**</br>
>The macros <code>END_SPEED_RPM</code>, <code>NOMINAL_SPEED_RPM</code>, and <code>MAXIMUM_SPEED_RPM</code> are specified in the header file <code>**userparms.h**</code> included in the project **pmsm.X.** The macros <code>NOMINAL_SPEED_RPM</code> and <code>MAXIMUM_SPEED_RPM</code> are defined as per the Motor manufacturer’s specifications. Exceeding manufacture specifications may damage the motor or the board or both.

## 5.3  Data visualization through X2C-Scope Plug-in of MPLAB X

X2C-Scope is a third-party plug-in in MPLAB X, which helps in real-time diagnostics. The application firmware comes with the initialization needed to interface the controller with the host PC to enable data visualization through the X2C-Scope plug-in. Ensure the X2C-Scope plug-in is installed. For more information on how to set up a plug-in, refer to either the [Microchip Developer Help page](https://microchipdeveloper.com/mplabx:tools-plugins-available) or the [web page.](https://x2cscope.github.io/docs/MPLABX_Plugin.html)
 
1. To establish serial communication with the host PC, connect a micro-USB cable between the host PC and **connector J16** on the development board. This interface is also used for programming.

2. Ensure the application is configured and running as described under section [5.2 Basic Demonstration](#52-basic-demonstration) by following steps 1 through 11.

3. Open the **X2C-Scope** window by selecting **Tools>Embedded>X2CScope.**
      <p align="left">
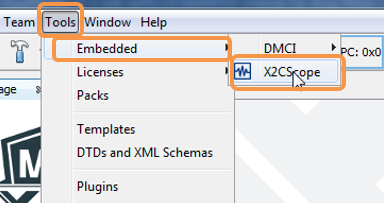
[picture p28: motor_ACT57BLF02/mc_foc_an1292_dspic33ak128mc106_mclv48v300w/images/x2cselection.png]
       </p>

4. **In the X2C-Scope Configuration** window, open the **Connection Setup** tab and click **Select Project.** This opens the drop-down menu **Select Project** with a list of opened projects. Select the specific project **pmsm** from the list of projects and click **OK.**
    <p align="left">
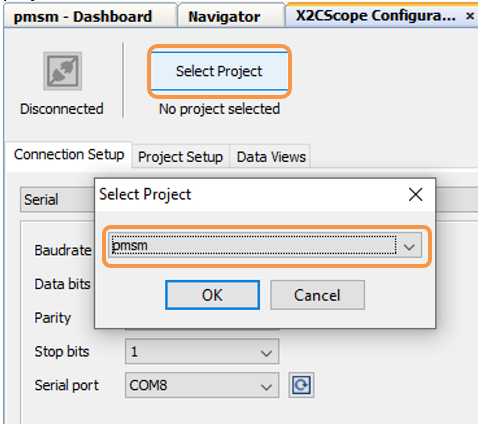
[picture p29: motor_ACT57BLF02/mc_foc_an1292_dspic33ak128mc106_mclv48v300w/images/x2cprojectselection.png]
    </p>

5. To configure and establish the serial communication for **X2C-Scope**, open the **X2CScope Configuration** window, click on the **Connection Setup** tab and:
     - Set **Baudrate** as **115200**, which is configured in the application firmware. 
     - Click on the **Refresh** button to refresh and update the list of the available Serial COM ports connected to the Host PC. 
     - Select the specific **Serial port** detected when interfaced with the development board. The **Serial port** depends on the system settings

    <p align="left">
     </p>

6. Once the **Serial port** is detected, click on **Disconnected** and turn to **Connected**, to establish serial communication between the Host PC and the board.
     <p align="left">
    </p>

7. Open the **Project Setup** tab in the **X2CScope Configuration** window and,
     - Set **Scope Sampletime** as the interval at which <code>X2CScopeUpdate()</code> is called. In this application, it is every <code>50µs.</code> 
     - Then, click **Set Values** to save the configuration.

      <p align="left">
      </p>

8.	Click on **Open Scope View** (in the **Data Views** tab of the **X2CScope Configuration** Window); this opens **Scope Window.**
     <p align="left">
      </p>
    	     
9. In the **Scope Window**, select the variables that must be watched. To do this, click on the **Source** against each channel, and a window **Select Variables** opens on the screen. From the available list, the required variable can be chosen. Ensure checkboxes **Enable** and **Visible** are checked for the variables to be plotted.
To view data plots continuously, uncheck **Single-shot.** When **Single-shot** is checked, it captures the data once and stops. The **Sample time factor** value multiplied by **Sample time** decides the time difference between any two consecutive data points on the plot.
    <p align="left">
    </p>

10.	Click on **SAMPLE**, then the X2C-Scope window plots variables in real-time, which updates automatically.
     <p align="left">
     </p>

11.	Click on **ABORT** to stop.
     <p align="left">
     </p>
 
 ## 6. REFERENCES:
For additional information, refer following documents or links.
1. AN1292 Application Note “[Sensorless Field Oriented Control (FOC) for a Permanent Magnet Synchronous Motor (PMSM) Using a PLL Estimator and Field Weakening (FW)](https://ww1.microchip.com/downloads/aemDocuments/documents/OTH/ApplicationNotes/ApplicationNotes/01292A.pdf)”
2. AN1299 Application Note “[Single-Shunt Three-Phase Current Reconstruction Algorithm for Sensorless FOC of a PMSM](http://ww1.microchip.com/downloads/en/appnotes/01299a.pdf)”
3. MCLV-48V-300W Development Board User’s Guide [(DS50003297)](https://ww1.microchip.com/downloads/aemDocuments/documents/MCU16/ProductDocuments/UserGuides/Motor-Control-Low-Voltage-48V-300W-Inverter-Board-Users-Guide-DS50003297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)
4. dsPIC33AK128MC106 Motor Control Dual In-Line Module (DIM) Information Sheet [(DS70005527)](https://ww1.microchip.com/downloads/aemDocuments/documents/MCU16/ProductDocuments/InformationSheet/dsPIC33AK128MC106-Motor-Control-Dual-In-Line-Module-DIM-Informatio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)
5. dsPIC33AK128MC106 Family datasheet [(DS70005539)](https://ww1.microchip.com/downloads/aemDocuments/documents/MCU16/ProductDocuments/DataSheets/dsPIC33AK128MC106-Family-Data-Sheet-DS70005539.pdf)
6. MPLAB® X IDE User’s Guide [(DS50002027)](https://ww1.microchip.com/downloads/en/DeviceDoc/50002027E.pdf) or [MPLAB® X IDE help](https://microchipdeveloper.com/xwiki/bin/view/software-tools/x/)
7. [MPLAB® X IDE installation](http://microchipdeveloper.com/mplabx:installation)
8. [MPLAB® XC-DSC Compiler installation](https://developerhelp.microchip.com/xwiki/bin/view/software-tools/xc-dsc/install/)
9. [Installation and setup of X2Cscope plugin for MPLAB X](https://x2cscope.github.io/docs/MPLABX_Plugin.html)
10. [Microchip Packs Repository](https://packs.download.microchip.com/)
11. [Programming and Debugging the dsPIC33A on MPLAB X IDE v6.20 and IPE v6.20](https://developerhelp.microchip.com/xwiki/bin/view/software-tools/ides/x/)

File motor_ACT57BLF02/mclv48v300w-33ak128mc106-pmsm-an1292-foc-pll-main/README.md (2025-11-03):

<picture>
    <source media="(prefers-color-scheme: dark)" srcset="images/microchip_logo_white_red.png">
    <source media="(prefers-color-scheme: light)" srcset="images/microchip_logo_black_red.png">
    Microchip Logo.
</picture>

## Sensorless FOC using PLL Estimator for PMSM : MCLV-48V-300W and dsPIC33AK128MC106 Motor Control DIM

## 1. INTRODUCTION
This document describes the setup requirements for driving a Permanent Magnet Synchronous Motor (PMSM) using Sensorless Field Oriented Control (FOC) and PLL Estimator Algorithm on the hardware platform [EV18H47A](https://www.microchip.com/en-us/development-tool/ev18h47a) "MCLV-48V-300W Development Board"  and [EV68M17A](https://www.microchip.com/en-us/development-tool/ev68m17a) "dsPIC33AK128MC106 Motor Control Dual In-line Module (DIM)".

For details about PLL estimator, refer to Microchip application note [AN1292](https://ww1.microchip.com/downloads/aemDocuments/documents/OTH/ApplicationNotes/ApplicationNotes/01292A.pdf) “Sensorless Field Oriented Control (FOC) for a Permanent Magnet Synchronous Motor (PMSM) Using a PLL Estimator and Field Weakening (FW)”
</br>

## 2. SUGGESTED DEMONSTRATION REQUIREMENTS

### 2.1 Motor Control Application Firmware Required for the Demonstration

To clone or download this application firmware on GitHub, 
- Navigate to the [main page of this repository](https://github.com/microchip-pic-avr-solutions/mclv48v300w-33ak128mc106-pmsm-an1292-foc-pll) and 
- On the tab **<> Code**, above the list of files in the right-hand corner, click Code, then from the menu, click **Download ZIP** or copy the repository URL to **clone.**
> **Note:** </br>
>In this document, hereinafter this firmware package is referred as **firmware.**
### 2.2 Software Tools Used for Testing the firmware

- MPLAB® X IDE **v6.25** 
- Device Family Pack (DFP): **dsPIC33AK-MC_DFP v1.1.109**
- Curiosity/Starter Kits Tool Pack : **PKOB4_TP v1.19.1503**
- MPLAB® XC-DSC Compiler **v3.21**
- MPLAB® X IDE Plugin: **X2C-Scope v1.7.0** 
> **Note:** </br>
>The software used for testing the firmware prior to release is listed above. It is recommended to use these or later versions of the tool for building the firmware. All previous versions of Device Family Packs (DFP) and Tool Packs can be downloaded from [Microchip Packs Repository.](https://packs.download.microchip.com/)
### 2.3 Hardware Tools Required for the Demonstration
- MCLV-48V-300W Development Board [(EV18H47A)](https://www.microchip.com/en-us/development-tool/ev18h47a)
- dsPIC33AK128MC106 Motor Control Dual In-line Module [(EV68M17A)](https://www.microchip.com/en-us/development-tool/ev68m17a)
- 24V Power Supply [(AC002013)](https://www.microchipdirect.com/dev-tools/AC002013)
- 24V 3-Phase Brushless DC Motor - Hurst DMA0204024B101 [(AC300022)](https://www.microchip.com/en-us/development-tool/AC300022) or,
- 24V 3-Phase Brushless DC Motor - Hurst DMB0224C10002 [(AC300020)](https://www.microchip.com/en-us/development-tool/AC300020) or,
- 24V 3-Phase Leadshine Servo Motor [(ELVM6020V24FH-B25-HD)](https://www.leadshine.com/product-detail/ELVM6020V24FH-B25-HD.html)

> **Note:** </br>
> All items listed above except Leadshine Servo Motor (ELVM6020V24FH-B25-HD) are available at [microchip DIRECT](https://www.microchipdirect.com/)
>- Hurst DMA0204024B101(AC300022) is referred as Hurst300 or Long Hurst in the firmware
>- Hurst DMB0224C10002(AC300020) is referred as Hurst075 or Short Hurst in the firmware
>- Leadshine Servo Motor ELVM6020V24FH-B25-HD is referred as leadshine24v in the firmware
</br>

## 3. HARDWARE SETUP
This section describes the hardware setup required for the demonstration.
> **Note:** </br>
>In this document, hereinafter the MCLV-48V-300W Development Board is referred as **development board**.

1. Motor currents are amplified on the MCLV-48V-300W development board; it can also be amplified by the amplifiers internal to the dsPIC33AK128MC106 on the DIM. The firmware and DIM are configured to sample and convert internal amplifier outputs (**'internal op-amp configuration'**) by default to measure the motor currents needed to implement FOC. **Table-1** summarizes the resistors to be populated and removed to convert the DIM from **‘internal op-amp configuration’** to **‘external op-amp configuration’** or vice versa.

     <p align="left" >
     </p>

2. Insert the **dsPIC33AK128MC106 Motor Control DIM** into the DIM Interface **connector J8** on the development board. Make sure the DIM is placed correctly and oriented before going ahead.

     <p align="left" >
     </p>

3. Connect the 3-phase wires from the motor to PHC, PHB, and PHA of the **connector J4**(no specific order), provided on the development board.

     <p align="left" >
      </p>

4. Plug the 24V power supply to **connector J1** on the development board. Alternatively, the development board can also be powered through connector J3.
      <p align="left">
      </p>

 5. The board has an onboard programmer **PICkit™ On Board (PKoBv4)** , which can be used for programming or debugging the microcontroller or dsPIC DSC on the DIM. To use the onboard programmer, connect a micro-USB cable between the Host PC and **connector J16** on the development board.
      <p align="left">
     </p>

 6. Alternatively, connect the Microchip programmer/debugger MPLAB® PICkit™ 5 In-Circuit Debugger[(PG164150)](https://www.microchip.com/en-us/development-tool/pg164150) between the Host PC used for programming the device and the **ICSP header J9** on the development board (as shown). Ensure that PICkit 5 is oriented correctly before proceeding.
      <p align="left">
       </p>
 </br>

## 4. SOFTWARE SETUP AND RUN
### 4.1 Setup: MPLAB X IDE and MPLAB XC-DSC Compiler
Install **MPLAB X IDE** and **MPLAB XC-DSC Compiler** versions that support the device **dsPIC33AK128MC106** and **PKoBv4.** The MPLAB X IDE, MPLAB XC-DSC Compiler, and X2C-Scope plug-in used for testing the firmware are mentioned in the [Motor Control Application Firmware Required for the Demonstration](#21-motor-control-application-firmware-required-for-the-demonstration) section. 

To get help on  

- MPLAB X IDE installation, refer [link](https://microchipdeveloper.com/mplabx:installation)
- MPLAB XC-DSC Compiler installation steps, refer [link](https://developerhelp.microchip.com/xwiki/bin/view/software-tools/xc-dsc/install/)

If MPLAB IDE v8 or earlier is already installed on your computer, then run the MPLAB driver switcher (Installed when MPLAB®X IDE is installed) to switch from MPLAB IDE v8 drivers to MPLAB X IDE drivers. If you have Windows 8 or 10, you must run the MPLAB driver switcher in **Administrator Mode**. To run the Device Driver Switcher GUI application as administrator, right-click on the executable (or desktop icon) and select **Run as Administrator**. For more details, refer to the MPLAB X IDE help topic **“Before You Begin: Install the USB Device Drivers (For Hardware Tools): USB Driver Installation for Windows Operating Systems.”**

### 4.2 Setup: X2C-SCOPE
X2C-Scope is a MPLAB X IDE plugin that allows developers to interact with an application while it runs. X2C-Scope enables you to read, write, and plot global variables (for motor control) in real-time. It communicates with the target using the UART. To use X2C-Scope, the plugin must be installed. To set up and use X2C-Scope, refer to the instructions provided on the [web page](https://x2cscope.github.io/docs/MPLABX_Plugin.html).

## 5.  BASIC DEMONSTRATION
### 5.1 Firmware Description
The firmware version needed for the demonstration is mentioned in the section [Motor Control Application Firmware Required for the Demonstration](#21-motor-control-application-firmware-required-for-the-demonstration) section. This firmware is implemented to work on Microchip’s Digital signal controller (dsPIC® DSC) **dsPIC33AK128MC106**. For more information, see the **dsPIC33AK128MC106 Family datasheet [(DS70005539)](https://ww1.microchip.com/downloads/aemDocuments/documents/MCU16/ProductDocuments/DataSheets/dsPIC33AK128MC106-Family-Data-Sheet-DS70005539.pdf)**.

The Motor Control Demo application uses a push button to start or stop the motor and a potentiometer to vary the speed of the motor. This Motor Control Demo Application configures and uses peripherals like PWM, ADC, UART, OP-AMP, CMP, DAC etc. For more details, refer to Microchip Application note **[AN1292](https://ww1.microchip.com/downloads/aemDocuments/documents/OTH/ApplicationNotes/ApplicationNotes/01292A.pdf), “Sensorless Field Oriented Control (FOC) for a Permanent Magnet Synchronous Motor (PMSM) Using a PLL Estimator and Field Weakening (FW)”** available on the [Microchip website](https://www.microchip.com/en-us/application-notes).

> **Note:**</br>
> The project may not build correctly in Windows OS if the Maximum path length of any source file in the project is more than 260 characters. In case the absolute path exceeds or nears the maximum length, do any (or both) of the following:
> - Shorten the directory name containing the firmware used in this demonstration. If you renamed the directory, consider the new name while reading the instructions provided in the upcoming sections of the document.
> - Place firmware in a location such that the total path length of each file included in the projects does not exceed the Maximum Path length specified. </br>
> Refer to MPLAB X IDE help topic **“Path, File, and Folder Name Restrictions”** for details. 

### 5.2 Basic Demonstration
Follow the below instructions, step by step, to set up and run the motor control demo application:

1. Start **MPLAB X IDE** and open the project **pmsm.X (File > Open Project)** with device selection **dsPIC33AK128MC106.**  
    <p align="left">
       </p>

2. Set the project **pmsm.X** as the main project by right-clicking on the project name and selecting **Set as Main Project** as shown. The project **pmsm.X** will then appear in **bold.**
    <p align="left">
     </p>

3. Open <code>**mc1_user_params.h** </code> (**pmsm.X > Header Files**) in the project **pmsm.X.**  
     - Ensure the macros <code>**OPEN_LOOP_FUNCTIONING</code> and <code>SINGLE_SHUNT</code>** are **undefined**
          
     - Firmware is configured to run with Hurst DMA0204024B101 Motor(Hurst300 or Long Hurst-[AC300022](https://www.microchip.com/en-us/development-tool/AC300022)) by default. **Define** the macro to **MOTOR 2** to run with Hurst DMB0224C10002 Motor(Hurst075 or Short Hurst-[AC300020](https://www.microchip.com/en-us/development-tool/AC300020)),or **define** the macro to **MOTOR 3** to run with Leadshine Servo Motor [(ELVM6020V24FH-B25-HD)](https://www.leadshine.com/product-detail/ELVM6020V24FH-B25-HD.html). All the Motors are tested under no load conditions. To achieve optimal performance under loaded conditions, the control parameters in the firmware may need additional tuning.
          
     - By default, the macro <code>**FLUX_WEAKENING_VARIANT**</code> is **defined** to **1**, enabling the flux weakening control through a PI controller that limits the voltage circle using voltage feedback. **Define** the macro to **2** to enable the flux weakening using reference speed feed-forward control based on PMSM steady state equations. The flux weakening can be disabled by **defining** the macro to **0**.
          
     - When internal amplifiers are used for current amplification (referred to as **internal op-amp configuration**), **define** the macro <code>**INTERNAL_OPAMP_CONFIG**</code>
          
     - Otherwise, if external amplifiers are used for current amplification (referred to as **external op-amp configuration**), undefine the macro <code>**INTERNAL_OPAMP_CONFIG**</code>
         

> **Note:**</br>
>The motor phase currents can be reconstructed from the DC Bus current by appropriately sampling it during the PWM switching period, called as single-shunt reconstruction algorithm. The firmware can be configured to demonstrate **the single shunt reconstruction algorithm** by defining the macro <code>**SINGLE_SHUNT**</code> in the header file <code>**mc1_user_params.h**</code> 
>For additional information, refer to Microchip application note **[AN1299](http://ww1.microchip.com/downloads/en/appnotes/01299a.pdf), “Single-Shunt Three-Phase Current Reconstruction Algorithm for Sensorless FOC of a PMSM.”**
>By default, the firmware uses phase currents measured across the phase shunt resistors on two of the half-bridges of the three-phase inverter (**‘dual shunt configuration’**) to implement FOC.

4. Right-click on the project **pmsm.X** and select **Properties** to open its **Project Properties** Dialog. Click the **Conf:[default]** category to reveal the general project configuration information. The development tools used for testing the firmware are listed in section [2.2 Software Tools Used for Testing the firmware.](#22-software-tools-used-for-testing-the-firmware)

     In the **Conf:[default]** category window: 
     - Ensure the selected **Device** is **dsPIC33AK128MC106.**
     - Select the **Connected Hardware Tool** to be used for programming and debugging. 
     - Select the specific Device Family Pack (DFP) from the available list of **Packs.** In this case, **dsPIC33AK-MC_DFP 1.1.109** is selected. 
     - Select the specific **Compiler Toolchain** from the available list of **XC-DSC** compilers. 
     In this case, **XC-DSC(v3.21)** is selected.
     - After selecting Hardware Tool and Compiler Toolchain, Device Pack, click the button **Apply**

     Please ensure that the selected MPLAB® XC-DSC Compiler and Device Pack support the device configured in the firmware

     <p align="left">
     </p>

5. Ensure that the checkbox **Load symbols when programming or building for production (slows process)** is checked under the **Loading** category of the **Project Properties** window.       
        
      <p align="left">
      </p>

     Also, go to **Tools > Options** , and
           
      <p align="left">
      </p>
      
    Open the  **Embedded > Generic Settings** tab and ensure that the **ELF debug session symbol load methodology (MIPS/ARM)** is selected as **Pre-procesed (Legacy)** from the drop down.
           
      <p align="left">
      </p>
6. To build the project (in this case, **pmsm.X**) and program the device dsPIC33AK128MC106, click **Make and Program Device Main project** on the toolbar
    <p align="left">
    </p>
  
7. If the device is successfully programmed, **LED1 (LD2)** will be **blinking**, indicating that the dsPIC® DSC is enabled.
    <p align="left">
     </p>

8. Run or stop the motor by pressing the push button **SW1.** The motor should start spinning smoothly in one direction in the nominal speed range. Ensure that the motor is spinning smoothly without any vibration. The LED **LED2(LD3)** is turned **ON** to show the button is pressed to start the motor.The specific motor was tested under no load conditions. To achieve optimal performance under loaded conditions, the control parameters in the firmware may need additional tuning.
     <p align="left">
     </p>
 
9. The motor speed can be varied using the potentiometer **(POT1).**
    <p align="left">
    </p>
 
10. Press the push button **SW2** to change the direction of rotation of motor.
     <p align="left">
     </p> 

11. Press the push button **SW1** to stop the motor.

>**Note:**</br>
>The macros <code>NOMINAL_SPEED_RPM</code> and <code>MAXIMUM_SPEED_RPM</code> are defined in the respective motor header files as per the Motor manufacturer’s specifications. Exceeding manufacture's specifications may damage the motor or the board or both.

## 5.3  Data visualization through X2C-Scope Plug-in of MPLAB X

X2C-Scope is a third-party plug-in in MPLAB X, which helps in real-time diagnostics. The application firmware comes with the initialization needed to interface the controller with the host PC to enable data visualization through the X2C-Scope plug-in. Ensure the X2C-Scope plug-in is installed. For more information on how to set up a plug-in, refer to either the [Microchip Developer Help page](https://microchipdeveloper.com/mplabx:tools-plugins-available) or the [web page.](https://x2cscope.github.io/docs/MPLABX_Plugin.html)
 
1. To establish serial communication with the host PC, connect a micro-USB cable between the host PC and **connector J16** on the development board. This interface is also used for programming.

2. Ensure the application is configured and running as described under section [5.2 Basic Demonstration](#52-basic-demonstration) by following steps 1 through 10.

3. Open the **X2C-Scope** window by selecting **Tools>Embedded>X2CScope.**
      <p align="left">
       </p>

4. **In the X2C-Scope Configuration** window, open the **Connection Setup** tab and click **Select Project.** This opens the drop-down menu **Select Project** with a list of opened projects. Select the specific project **pmsm** from the list of projects and click **OK.**
    <p align="left">
    </p>

5. To configure and establish the serial communication for **X2C-Scope**, open the **X2CScope Configuration** window, click on the **Connection Setup** tab and:
     - Set **Baudrate** as **115200**, which is configured in the application firmware. 
     - Click on the **Refresh** button to refresh and update the list of the available Serial COM ports connected to the Host PC. 
     - Select the specific **Serial port** detected when interfaced with the development board. The **Serial port** depends on the system settings

    <p align="left">
     </p>

6. Once the **Serial port** is detected, click on **Disconnected** and turn to **Connected**, to establish serial communication between the Host PC and the board.
     <p align="left">
    </p>

7. Open the **Project Setup** tab in the **X2CScope Configuration** window and,
     - Set **Scope Sampletime** as the interval at which <code>X2CScopeUpdate()</code> is called. In this application, it is every <code>50µs.</code> 
     - Then, click **Set Values** to save the configuration.

      <p align="left">
      </p>

8.	Click on **Open Scope View** (in the **Data Views** tab of the **X2CScope Configuration** Window); this opens **Scope Window.**
     <p align="left">
      </p>
    	     
9. In the **Scope Window**, select the variables that must be watched. To do this, click on the **Source** against each channel, and a window **Select Variables** opens on the screen. From the available list, the required variable can be chosen. Ensure checkboxes **Enable** and **Visible** are checked for the variables to be plotted.
To view data plots continuously, uncheck **Single-shot.** When **Single-shot** is checked, it captures the data once and stops. The **Sample time factor** value multiplied by **Sample time** decides the time difference between any two consecutive data points on the plot.
    <p align="left">
    </p>

10.	Click on **SAMPLE**, then the X2C-Scope window plots variables in real-time, which updates automatically.
     <p align="left">
     </p>

11.	Click on **ABORT** to stop.
     <p align="left">
     </p>
 
 ## 6. REFERENCES:
For additional information, refer following documents or links.
1. AN1292 Application Note “[Sensorless Field Oriented Control (FOC) for a Permanent Magnet Synchronous Motor (PMSM) Using a PLL Estimator and Field Weakening (FW)](https://ww1.microchip.com/downloads/aemDocuments/documents/OTH/ApplicationNotes/ApplicationNotes/01292A.pdf)”
2. AN1299 Application Note “[Single-Shunt Three-Phase Current Reconstruction Algorithm for Sensorless FOC of a PMSM](http://ww1.microchip.com/downloads/en/appnotes/01299a.pdf)”
3. MCLV-48V-300W Development Board User’s Guide [(DS50003297)](https://ww1.microchip.com/downloads/aemDocuments/documents/MCU16/ProductDocuments/UserGuides/Motor-Control-Low-Voltage-48V-300W-Inverter-Board-Users-Guide-DS50003297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)
4. dsPIC33AK128MC106 Motor Control Dual In-Line Module (DIM) Information Sheet [(DS70005527)](https://ww1.microchip.com/downloads/aemDocuments/documents/MCU16/ProductDocuments/InformationSheet/dsPIC33AK128MC106-Motor-Control-Dual-In-Line-Module-DIM-Informatio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)
5. dsPIC33AK128MC106 Family datasheet [(DS70005539)](https://ww1.microchip.com/downloads/aemDocuments/documents/MCU16/ProductDocuments/DataSheets/dsPIC33AK128MC106-Family-Data-Sheet-DS70005539.pdf)
6. MPLAB® X IDE User’s Guide [(DS50002027)](https://ww1.microchip.com/downloads/en/DeviceDoc/50002027E.pdf) or [MPLAB® X IDE help](https://microchipdeveloper.com/xwiki/bin/view/software-tools/x/)
7. [MPLAB® X IDE installation](http://microchipdeveloper.com/mplabx:installation)
8. [MPLAB® XC-DSC Compiler installation](https://developerhelp.microchip.com/xwiki/bin/view/software-tools/xc-dsc/install/)
9. [Installation and setup of X2Cscope plugin for MPLAB X](https://x2cscope.github.io/docs/MPLABX_Plugin.html)
10. [Microchip Packs Repository](https://packs.download.microchip.com/)
11. [Programming and Debugging the dsPIC33A on MPLAB X IDE v6.20 and IPE v6.20](https://developerhelp.microchip.com/xwiki/bin/view/software-tools/ides/x/)

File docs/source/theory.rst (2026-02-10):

The Theory behind the MC-Dyno
==============================

.. contents::
   :local:
   :depth: 2

1. Overview
-----------

The MC-Dyno is a motor dynamometer built from two motor-control systems coupled
shaft-to-shaft: a motor-under-test (DUT) and a dynamometer motor that applies a
controlled load. The dyno motor acts as an active brake, allowing you to command
load profiles and observe how the DUT responds in speed, torque, and current.

1.1 Dyno vs DUT Roles
~~~~~~~~~~~~~~~~~~~~~

- **DUT side:** runs the control algorithm you want to test (speed or torque control).
- **Dyno side:** applies a controllable mechanical load to the DUT motor.
- **Mechanical coupling:** transfers torque between the two machines so the dyno can
  load the DUT and absorb power.

1.2 Energy Flow and the DC Link
~~~~~~~~~~~~~~~~~~~~~~~~~~~~~~~

In a typical setup both control boards share a single DC power supply. When the
DUT motor produces power, the dyno side absorbs that mechanical energy and the
system returns electrical energy to the shared DC link. Using a single supply and
shared DC link keeps the bus voltage stable during regenerative operation.

2. Control Concepts
-------------------

2.1 Closed-Loop Control
~~~~~~~~~~~~~~~~~~~~~~~

The demo uses closed-loop control to regulate speed and torque. On the DUT side
this shows how the controller reacts to commanded setpoints and load changes. On
the dyno side it provides the load torque profile that the DUT must overcome.

For the closed loop control it uses a FOC scheme. 

Here are some details on some of the different blocks: 

**Speed_pi block**

Speed PI block diagram

This diagram represents the speed regulation block through a PI (Proportional-Integral) controller. The main function
of this block is to keep the speed of the permanent magnet motor (PMSM) compliant with the reference value,
compensating for any differences.

Input:

- Reference speed (``omega_ref``): the desired speed command.
- Real speed (``omega_real``): measured actual motor speed.
- Speed error (``omega_ref - omega_real``): the error used by the PI controller to compute corrective action.

Output:

- Control signal (``Tcmd``): PI output sent to the motor to correct speed by adjusting torque-producing current.

**Startup Block**

Startup block diagram

The diagram shows the block that manages the start of the engine control system. Its main function is to ensure
safe engine start, verifying that all conditions are ready before activating the FOC (Field-Oriented Control) control in
normal mode.

Input:

- Startup signal: indicates when the system should start operating, activating the startup process.
- Initial rotor position: required to correctly initialize the control.
- Voltage and current parameters: used to monitor the motor status and confirm it is ready to start.

Output:

- FOC enable signal: sent when startup is complete to enable normal control.
- Starting current: a suitable current to start the motor without overcurrent or instability.

**Superblock Subsystem**

Ramp up generator subsystem

The subsystem shown in the image manages the generation of a ramp up signal for controlling the position or speed
of the motor. It is used to obtain a gradual and controlled start. The detailed operation of the main blocks is described
below:

- Sign and Multiplier Block: input signal 2 passes through a Sign block to determine its sign, then is multiplied by a
  constant (1.0) to maintain the correct direction.
- Ramp Generator: produces a signal increasing linearly over time, with an enable parameter to activate or deactivate it.
- Ramp Up Position Generator: creates a controlled position profile for engine start, reducing sudden movements.
- Initializations and Conversions: input 1 is converted and initialized to zero to establish an initial reference condition.
- System Protection: the Saturation block limits signal values to prevent overloads and dangerous movements.
- Output: the generated control signal used for controlling a motor or mechanical system.

**Clarke_Park_MCHP Block**

Clarke Park MCHP block diagram

This diagram represents the Clarke-Park transformation block, which performs two important
mathematical conversions for the vector control of the motor. Its role is fundamental to go from
ABC coordinates (three-phase) to dq coordinates (synchronized with the rotor), facilitating the
control of torque and magnetic flux.

Input:

- Three-phase currents (``Ia``, ``Ib``, ``Ic``): measured motor phase currents, transformed for FOC control.
- Rotor angle (``theta``): rotor position angle required for the Park transform, synchronizing control with the rotor.

Output:

- Currents in dq coordinates (``Id``, ``Iq``): allow direct control of magnetic flux (``Id``) and torque (``Iq``).

2.2 Load Profiles
~~~~~~~~~~~~~~~~~

Load profiles are used to demonstrate dynamic behavior. Examples include:

- **Constant torque** for a steady load.
- **Trapezoidal load** for time-varying torque changes.
- **Unbalanced / disturbance cases** to highlight transient response.

3. What the Demo Shows
----------------------

- Stable closed-loop control in speed and torque.
- The DUT response to dynamic load profiles.
- How current changes under added disturbance (useful for predictive-maintenance
  concepts and anomaly detection demonstrations).

4. Observability and Scaling
----------------------------

The system exposes internal signals (currents, torque, speed) through the scope
interface. Use the model report scaling factors to convert fixed-point values to
real units when presenting data.

**Typical signals to watch**

- Quadrature current (torque-producing current)
- Direct current (flux component)
- Phase current
- Electrical or mechanical speed
- Dyno torque (if available in the model)

5. Operating Envelope and Safety
--------------------------------

- Keep within the board and motor ratings.
- Maintain proper shaft alignment to minimize mechanical stress.
- Use a single DC supply and shared DC link to avoid overvoltage during braking.
- Apply disturbances only at low speed and under controlled conditions.

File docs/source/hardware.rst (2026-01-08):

Hardware & Connections
======================

Summarise the main hardware components and jumper settings:

- MCLV-2 or other supported boards
- SAME54 PIM / other PIMs
- Hurst 300 motor (with QEI encoder)
- RS232 connections
- Optional IGaT display (EV14C17A) connected and programmed separately
- Optional torque sensor

List key jumper positions and wiring notes copied or summarised from the README.

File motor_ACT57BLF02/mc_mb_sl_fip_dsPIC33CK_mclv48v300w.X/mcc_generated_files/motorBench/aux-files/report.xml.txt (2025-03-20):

<?xml version="1.0"?>
<report xmlns="http://www.microchip.com/motorBench/xml/report/0.1" >
  <metadata>
    <source>
       <title>Motor Control Application Framework</title>
       <version>R7/RC37</version>
       <commit>116330</commit>
       <build_time>2023 Feb 09 16:21</build_time>
     </source>
   </metadata>
<motor>
  <item>
    <key>id</key>
    <description>motor ID</description>
    <value>Rika Fan</value>
  </item>
  <item>
    <key>poleCount</key>
    <description>number of poles</description>
    <value>8</value>
  </item>
  <item>
    <key>polePairs</key>
    <description>number of pole pairs</description>
    <value>4.0</value>
  </item>
  <item>
    <key>R</key>
    <description>stator resistance</description>
    <value>0.5</value>
    <units>ohms line-neutral</units>
  </item>
  <item>
    <key>Rll</key>
    <description>stator resistance</description>
    <value>1.0</value>
    <units>ohms line-line</units>
  </item>
  <item>
    <key>L</key>
    <description>stator inductance</description>
    <value>0.000325</value>
    <units>H line-neutral</units>
  </item>
  <item>
    <key>Lll</key>
    <description>stator inductance</description>
    <value>0.00065</value>
    <units>H line-line</units>
  </item>
  <item>
    <key>Ld</key>
    <description>d-axis stator inductance</description>
    <value>0.0003</value>
    <units>H line-neutral</units>
  </item>
  <item>
    <key>Ldll</key>
    <description>d-axis stator inductance</description>
    <value>0.0006</value>
    <units>H line-line</units>
  </item>
  <item>
    <key>Lq</key>
    <description>q-axis stator inductance</description>
    <value>0.00035</value>
    <units>H line-neutral</units>
  </item>
  <item>
    <key>Lqll</key>
    <description>q-axis stator inductance</description>
    <value>0.0007</value>
    <units>H line-line</units>
  </item>
  <item>
    <key>Ke</key>
    <description>back-EMF constant</description>
    <value>0.03727435242757741</value>
    <units>V/(rad/s) line-neutral 0-pk</units>
    <altunit><value>3.903361058</value><units>V/KRPM line-neutral 0-pk</units></altunit>
  </item>
  <item>
    <key>Kell</key>
    <description>back-EMF constant</description>
    <value>0.06456107222379238</value>
    <units>V/(rad/s) line-line 0-pk</units>
    <altunit><value>6.760819673</value><units>V/KRPM line-line 0-pk</units></altunit>
  </item>
  <item>
    <key>Ke_datasheet</key>
    <description>back-EMF constant</description>
    <value>4.780621437538287</value>
    <units>Vrms/KRPM line-line</units>
  </item>
  <item>
    <key>B</key>
    <description>viscous damping</description>
    <value>3.996146206696033e-05</value>
    <units>Nm/(rad/s)</units>
  </item>
  <item>
    <key>Tf</key>
    <description>Coulomb friction</description>
    <value>0.0143238350133147</value>
    <units>Nm</units>
  </item>
  <item>
    <key>J</key>
    <description>inertia</description>
    <value>0.0002842855142191637</value>
    <units>Nm/(rad/s^2)</units>
  </item>
  <item>
    <key>omega_m_max</key>
    <description>maximum velocity</description>
    <value>314.1592653589793</value>
    <units>rad/s</units>
    <altunit><value>3000.000000085746</value><units>RPM</units></altunit>
  </item>
  <item>
    <key>omega_m1</key>
    <description>nominal (base) velocity</description>
    <value>282.7433388230814</value>
    <units>rad/s</units>
    <altunit><value>2700.000000077172</value><units>RPM</units></altunit>
  </item>
  <item>
    <key>omega_e1</key>
    <description>nominal electrical frequency</description>
    <value>1130.9733552923256</value>
    <units>rad/s</units>
    <altunit><value>10800.000000308687</value><units>RPM</units></altunit>
  </item>
  <item>
    <key>I1</key>
    <description>rated current</description>
    <value>2.0</value>
    <units>A</units>
  </item>
  <item>
    <key>V1</key>
    <description>nominal voltage</description>
    <value>10.539074857841465</value>
    <units>V line-neutral</units>
  </item>
  <item>
    <key>V1ll</key>
    <description>nominal voltage</description>
    <value>18.25421311855316</value>
    <units>V line-line</units>
  </item>
  <item>
    <key>T1</key>
    <description>rated torque</description>
    <value>0.11182305728273223</value>
    <units>Nm</units>
  </item>
  <item>
    <key>P1</key>
    <description>rated power</description>
    <value>31.617224573524396</value>
    <units>W</units>
  </item>
</motor>
</report>

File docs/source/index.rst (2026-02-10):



MC-Dyno
=========

The **MC-Dyno** is an **open** project that includes both software and hardware to enable anyone 
to build their own motor dynamometer for testing and tuning motor-control algorithms.
The project supports both high-voltage and low-voltage configurations on the dyno side, 
and can test virtually **any electric motor** on the DUT (Device-Under-Test) side.

.. admonition:: By the way...

   “Dyno” is short for *dynamometer*. In this project the dyno is implemented using a 
   **PMSM motor** which must have an encoder. This motor is connected to a control board
   running the MC-Dyno software, and the control board, is connected to a **PC running Scilab/XCOS**
   or external an controller (for example the :doc:`IGAT <igat>`) for interfacing with it. 
   In a motor-dyno setup, the motor is the device that *produces* mechanical power, 
   while the dyno is the machine that *absorbs* mechanical power and measures the motor’s performance.
   Using this configuration you can apply a controllable mechanical load to the motor-under-test
   and observe its response (torque, speed, power, efficiency, thermal behavior, etc.).
   For basic characterization a dedicated torque sensor is not required. Because the **dyno is “smart”**
   (motor-as-brake), you can simulate **different load profiles** and dynamic conditions, enabling more
   meaningful testing than with simple passive loads.

Get Inspired & Build your own MC-Dyno
---------------------------------------

Here are a few example builds to spark ideas. Use MC-Dyno as a base and adapt it to your own
motors and mechanics.

.. list-table::
   :widths: 33 33 33 33 33 33 33
   :align: center

   * - Desktop MC-Dyno build
     - High-voltage rack dyno
     - Differential Coupling Torque Sensor Dyno
     - Differential Coupling Torque Sensor Dyno
     - Differential Coupling Torque Sensor Dyno
     - Suitcase MC-Dyno build
     - Example with Torque Sensor
   * - Desktop BLDC dyno for low-voltage testing
     - High-voltage inverter + PMSM test bench
     - Differential coupling for cheap torque measurement
     - Low Votlage Dyno but High Voltage DUT
     - Exhibition Ready Demo
     - Suitcase MC-Dyno build
     - Example with Torque Sensor

--------

.. toctree::
   :maxdepth: 1
   :caption: Contents:

   make_your_MC_Dyno
   Device_Under_Test
   theory
   igat
   usage

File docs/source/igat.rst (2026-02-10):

IGaT Display (EV14C17A)
=======================

The Integrated Graphics and Touch (IGaT) Curiosity Evaluation Kit (EV14C17A)
is used as an optional standalone display alongside the Dyno. It runs on a
SAM E51 MCU and is programmed independently from the dyno controller.

Here is a small video showing the capabilities of the board: https://youtu.be/NBVHWmz8veU

Firmware Location
-----------------

The display HEX lives in:

``MCDyno/igat_ev14c17a/doc/standalone/ATSAME51J20A_MC_Dyno_08_01_2026_IGAT.hex``

Download
--------

:download:`Download IGaT HEX <_downloads/ATSAME51J20A_MC_Dyno_08_01_2026_IGAT.hex>`

Programming Steps
-----------------

1. Connect a microUSB cable to the EV14C17A debug port.
2. Open MPLAB IPE and select the ATSAME51PJ20A device.
3. Program the HEX from ``doc/standalone/``.
4. Reset the board to run the UI.

Programming the IGaT HEX

Final Result
------------

IGaT display final result

More info on the kit:
https://www.microchip.com/en-us/development-tool/ev14c17a

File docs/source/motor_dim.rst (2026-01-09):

Motor DIM HEX (MCLV-48V-300W)
=============================

These HEX files target the motor-side control DIM installed on the
MCLV-48V-300W Development Board (EV18H47A). They are used to showcase different
motor-control algorithms on the dyno.

Example DIM: dsPIC33CK256MP508 Motor Control DIM (EV62P66A)
https://www.microchip.com/en-us/development-tool/ev62p66a

HEX Location
------------

``motor_ACT57BLF02/mclv48v300w_dim_hex/doc/standalone/``

Downloads
---------

.. container:: motor-dim-downloads

   :download:`Single-shunt (dsPIC33AK128MC106 DIM) <_downloads/dsPIC33AK128MC106_MCHP_Dyno_08_01_2026_SingleShunt_DIM.hex>`

   :download:`ZS/MT (dsPIC33CK256MP508 DIM) <_downloads/dsPIC33CK256MP508_MCHP_Dyno_08_01_2026_ZSMT_DIM.hex>`

   :download:`X2C (dsPIC33CK256MP508 DIM) <_downloads/dsPIC33CK256MP508_MCHP_Dyno_08_01_2026_X2C_DIM.hex>`

   :download:`QuickSpin (ATSAME54P20A DIM) <_downloads/ATSAME54P20A_MCHP_Dyno_08_01_2026_QuickSpin_DIM.hex>`

   :download:`StreamAnalyze (ATSAME54P20A DIM) <_downloads/ATSAME54P20A_MCHP_Dyno_08_01_2026_StreamAnalyze_DIM.hex>`

Algorithm Notes
---------------

DIM mapping:

- Single-shunt demo runs on the dsPIC33AK128MC106 DIM.
- ZS/MT and X2C demos run on the dsPIC33CK256MP508 DIM.

Single-shunt current measurement (MCAF R8):

- Samples the DC-link current twice in a single PWM period and reconstructs
  phase currents based on the inverter switching state.
- Requires a dedicated, high-priority ADC ISR and a minimum switching-state
  window (t_sample + dead time).
- For estimators other than ZS/MT, use single update in Dual Edge Center
  Aligned PWM mode.

Zero-Speed / Maximum Torque (ZS/MT) Estimator

ZS/MT is a sensorless position and speed estimation algorithm specifically
designed to operate where back-EMF based estimators fail, at zero and ultra-low
speeds.

Operating Principle - High-Frequency Signal Injection

Unlike PLL-type estimators, ZS/MT is intrusive: it injects a high-frequency
excitation voltage into the stator and measures the motor's response. This
leverages motor saliency to determine rotor angle even at standstill.

Motor Requirements (Saliency)

ZS/MT requires a motor with significant Ld != Lq saliency. It is thus primarily
intended for IPMSM machines, where q-axis inductance is notably higher than
d-axis inductance.

Startup Sequence - IPC for Zero-Speed Torque Production

To deliver torque from standstill, ZS/MT uses a startup procedure termed
"ZS/MT + Initial Position Correction (IPC)", allowing the controller to
correctly align the stator field before any mechanical motion begins.

Hybrid Operation - Low-Speed to High-Speed Transition

Because the injected signal consumes voltage headroom, ZS/MT cannot achieve the
absolute maximum speed by itself. In practice, it is combined with a back-EMF
estimator (for example, PLL) using a hybrid scheme (for example, "Minotaur
hard-switch") to allow:

- ZS/MT for 0-to-low-speed operation
- PLL for mid-to-high-speed operation

Tuning and Configuration Parameters

Reference hardware:
https://www.microchip.com/en-us/development-tool/ev18h47a

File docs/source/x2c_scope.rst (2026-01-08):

Using X2C Scope
===============

Explain how to connect and monitor signals:

1. Start X2C Scope.
2. Select the correct COM port.
3. Configure the sample time factor.
4. Press *Sample* to start acquiring data.

Add a short table of useful signals to watch (speed, torque, mode flags, etc.).

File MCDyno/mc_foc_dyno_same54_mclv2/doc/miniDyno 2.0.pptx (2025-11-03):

## miniDyno 2.0

- 01/2023

- Christoph Baumgartner

## The WHY?

- Easy Load testing without complicated application specific testbenches
- Algorithm testing
  - Different load profiles for sensorless algorithms
- AI/ML
  - Capture data for model training
  - Test different anomaly scenarios

## miniDyno 2.0 features

- 4Q operation (CW/CCW, motor/break)
  - DYNO
    - Constant load from potentiometer
    - Constant load from variable
    - Trapezoidal load (variables: frequency, raising/falling ramp, high/low value)
    - Fan load (k*n²[rpm], variable:k
    - Sine load ( variable: frequency, amplitude, offset)
    - Angle dependent loads ( electrical/mechanical)
      - 3 different table dependent load profiles (variables: amplitude and offset)
        - Unbalanced load (constant + sine)
        - Broken bearing (constant + rectangle)
        - Triangle ( constant + triangle)
      - Various compressor load profiles possible
  - MOTOR
    - Constant torque
    - Constant speed
      - Potentiometer
      - Variable
      - Trapezoidal (variables: frequency, raising/falling ramp, high/low value)


## miniDyno 2.0

dyno / generator / break / motor


motor


Loadprofile
0 = pot
1 = constant
2 = trapizoid
3 = fan
4 = sine
5 = angle dependent

DUT

UART


connect the powersupply lines to make sure the energy created from the generator is used somewhere

## Dual usage: SCILAB / X2C or Standalone

- miniDyno 2.0 usage
  - Standalone
    - Microchip programmer (ICD4, PICKit4, SNAP)
    - Software to program a hex file (MPLAB X or IPE)
    - No SCILAB, X2C and XC32 compiler required
  - SCILAB/X2C environment requirements
    - Scilab 6.1.1 + X2C 6.4
    - MPLAB X development environment (MPLAB X 6, Harmony3, XC32 free)
    - Microchip programmer (ICD4, PICKit4, SNAP)

## How to use the X2C based DYNO standalone

- Harware setup:
  - MCLV-2
  - ATSAME54
  - Hurst300 motor with encoder
  - RS232 cable
- Software setup
  - Microchip programmer (SW and HW)

ATTENTION:
Make sure the DYNO board power is connected to the motor board!

- Settings
  - JP1,2,3 -> Curr
  - JP4,5 -> UART
  - M1 – red
  - M2 – white
  - M3 – black
  - HA – QEI white
  - HB – QEI blue

## Firmware:

- Bitbucket
  - https://bitbucket.microchip.com/projects/X2C/repos/mc_foc_dyno_same54_mclv2/
- Move to [..\mc_foc_dyno_same54_mclv2\doc\standalone]
- Program [MC_FOC_DYNO_SAME54_MCLV2.X.production.hex] onto your SAME54 PIM
- Disconnect the programmer and reset the MCLV-2 board
- Execute [start.bat]


2: press the connect icon


3: change to [Model] tab

1: select your COM port

## miniDyno 2.0 setup

Magtrol TS105/011
torque sensor (optional)

Computer outline

miniDyno

motor

## Unified motor bracket:


- OpenSCAD design
- Same basic dimensions
- Motor mounting can be adjusted
- 3D printable
  - PLA
  - Layer 0.2mm
  - Infill 60%
..\mc_foc_dyno_same54_mclv2\doc\3Dparts

## Unified motor bracket:


## Future enhancements:

- Motor position control (for ZSMT tuning)
- Standalone GUI
- Using torquesensor for calibration
  - Real torquecontrol
- Add input/output power measurement
- MCHV-2/3 version in preparation
- Porting to MCLV-48V-300W

## Modify [Dyno] paramters – torque_profile


torque_mode
0: Constant load: potentiometer
1: Constand load:
[const_torque:Value]
2: Trapizoid load:
[t_load_f:Value]
[t_load_high:Value]
[t_load_low:Value]
[t_load_rate:Tr]
[t_load_rate:Tf]
3: Fan load:
[fan_gain:Gain]
4: Sine load:
[sine_A:Value]
[Sin_f:Value]
[Sin_load:fmax]
[Sin_load:Offset]
5: unbalanced load:
[GainT5:Value]
[ConstT5:Value]
6: broken bearing:
[GainT6:Value]
[ConstT6:Value]
7: triangle:
[GainT7:Value]
[ConstT7:Value]

## Modify [Motor] paramters – torque_profile


speed_mode
0: Constant speed: potentiometer
1: Constand speed:
[const_speed:Value]
2: Trapizoid load:
[t_speed_f:Value]
[t_ speed _high:Value]
[t_ speed _low:Value]
[t_ speed _rate:Tr]
[t_speed_rate:Tf]
[motor_torquemode]
1=speed control
0=torque control
Torquevalue
[const_torque_mode:Value]
Switch between Dyno/Motor
[DynoMotor]
1=Dyno
0=Motor

## Scope


Start Scope


Set „Sample Time Factor“
Press the „Sample“ Button to monitor signals.

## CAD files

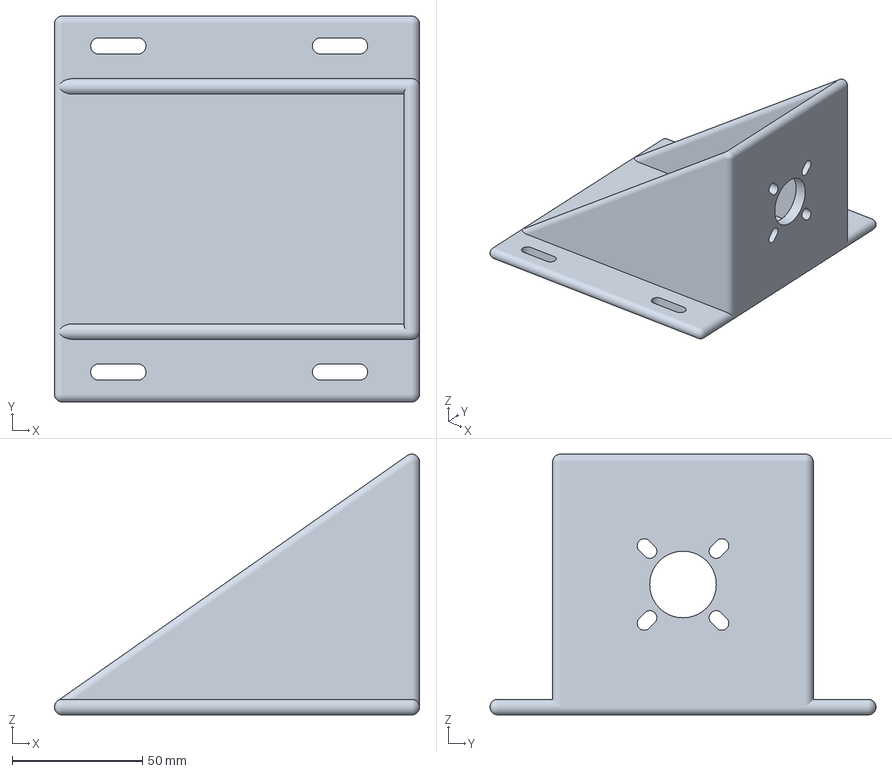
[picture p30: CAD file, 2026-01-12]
3Dparts/openSCAD/EBM_EC63.20_unified_V1_00.3mf
140.0 x 148.0 x 100.0 mm

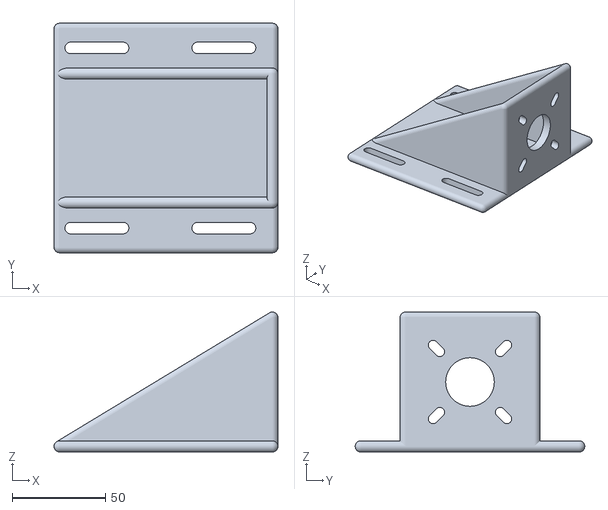
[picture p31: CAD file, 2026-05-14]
3Dparts/STL/Hurst_blue_wedge_V1_00.stl
120.0 x 123.0 x 75.0

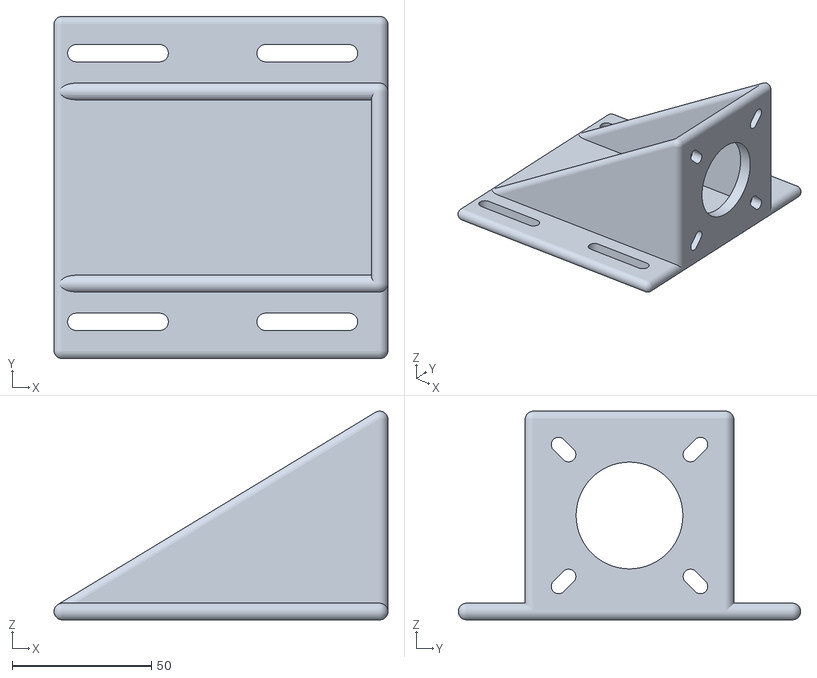
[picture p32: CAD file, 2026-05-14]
3Dparts/STL/ACT57BLF_blue_wedge_V1_00.stl
120.0 x 123.0 x 75.0

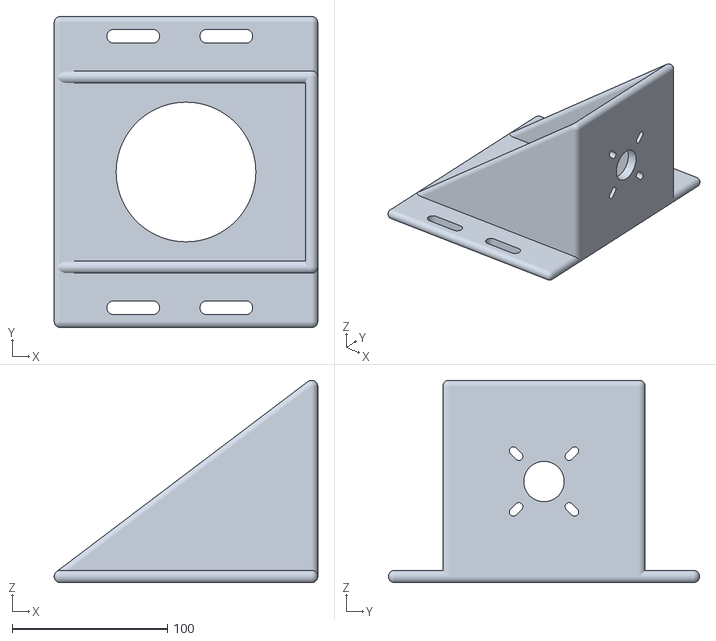
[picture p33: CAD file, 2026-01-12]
3Dparts/STL/Hurst_big bracket_V1_00.stl
170.0 x 200.5 x 130.5

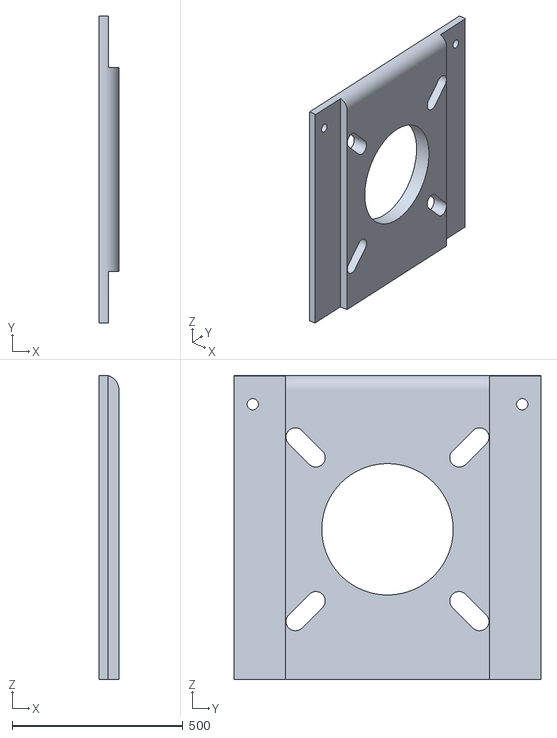
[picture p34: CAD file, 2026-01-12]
3Dparts/STL/ACT-Flat-Adapter.stl
58.0 x 900.0 x 892.7

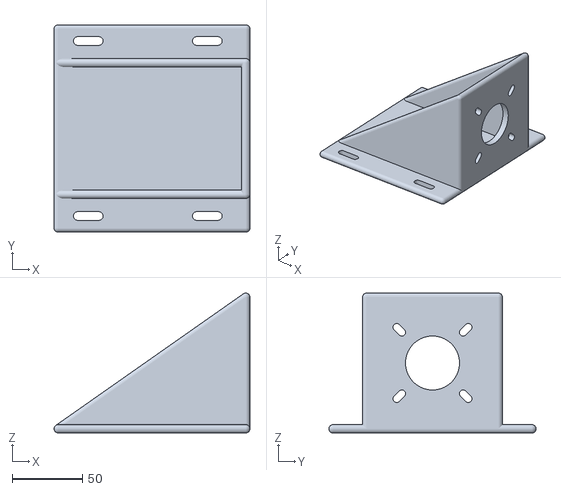
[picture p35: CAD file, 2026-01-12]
3Dparts/STL/ACT_57BLF0x_unified_V1_00.stl
140.0 x 148.0 x 100.0

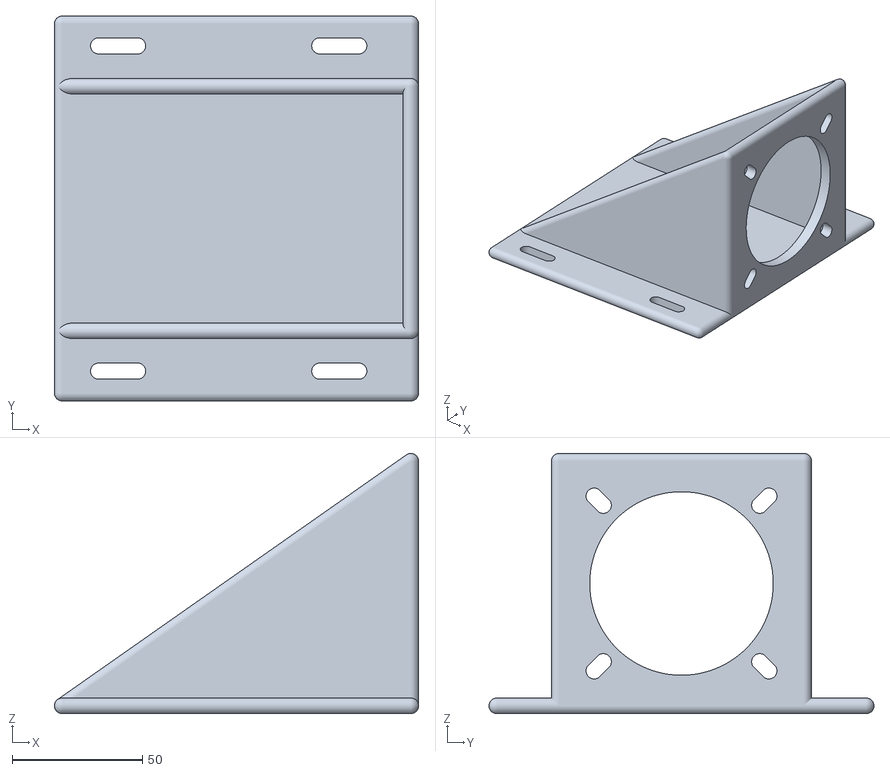
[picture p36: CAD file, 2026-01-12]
3Dparts/STL/Elra_IPM80_unified_V1_00.stl
140.0 x 148.0 x 100.0

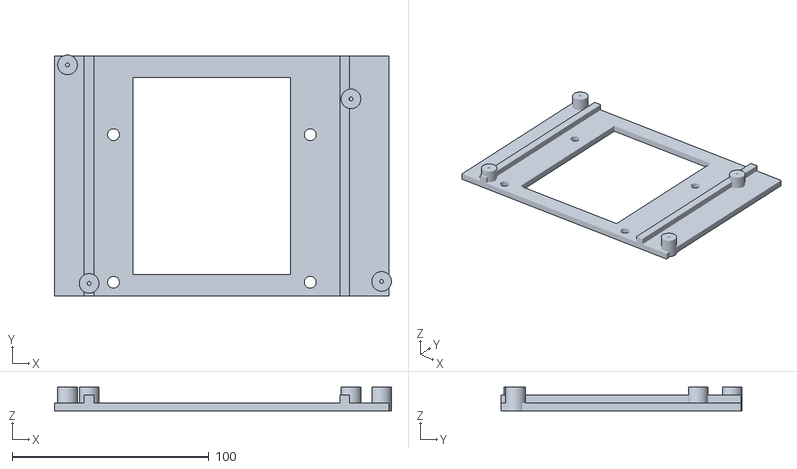
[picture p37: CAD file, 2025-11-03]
3Dparts/STL/MCLV2_TnutR01.stl
171.3 x 122.5 x 12.0

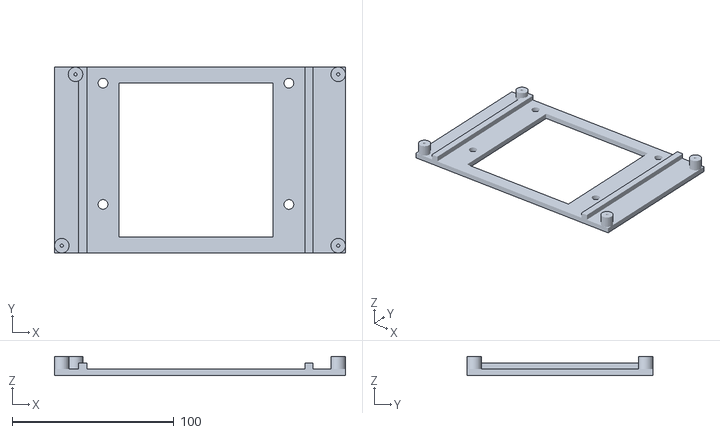
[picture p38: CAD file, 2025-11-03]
3Dparts/STL/MCLV48_300_TnutR01.stl
180.0 x 115.0 x 12.0

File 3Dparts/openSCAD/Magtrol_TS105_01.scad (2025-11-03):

// template.scad


$fn=60;

// variables



thickness = 4.5;

main();


module main()
{
    

    difference(){
        plus();
        minus();

    }
}


module plus()
{ 
    translate([0,0,thickness/2])rotate([0,0,0])cube([65+25,49+30,thickness],true);
 //   translate([0,0,12])rotate([0,0,0])cylinder(l1,12/2,11.8/2);
}

module minus()
{
    hull()
    {
        translate([25+12.5,15+15,0])rotate([0,0,0])cylinder(thickness,5.5/2,5.5/2);
        translate([25+12.5,-15-15,0])rotate([0,0,0])cylinder(thickness,5.5/2,5.5/2);
    }
    
    hull()
    {
        translate([-25-12.5,15+15,0])rotate([0,0,0])cylinder(thickness,5.5/2,5.5/2);
        translate([-25-12.5,-15-15,0])rotate([0,0,0])cylinder(thickness,5.5/2,5.5/2);
    }
    
    translate([25,15,0])rotate([0,0,0])cylinder(3.7,9.4/2,9.4/2,$fn=6);
    translate([25,-15,0])rotate([0,0,0])cylinder(3.7,9.4/2,9.4/2,$fn=6);
    translate([-25,15,0])rotate([0,0,0])cylinder(3.7,9.4/2,9.4/2,$fn=6);
    translate([-25,-15,0])rotate([0,0,0])cylinder(3.7,9.4/2,9.4/2,$fn=6);
    
    translate([25,15,0])rotate([0,0,0])cylinder(thickness,5.5/2,5.5/2);
    translate([25,-15,0])rotate([0,0,0])cylinder(thickness,5.5/2,5.5/2);
    translate([-25,15,0])rotate([0,0,0])cylinder(thickness,5.5/2,5.5/2);
    translate([-25,-15,0])rotate([0,0,0])cylinder(thickness,5.5/2,5.5/2);
}

module cube_r(x,y,z,r)
{
    hull()
    {
        translate([r,r,r])cube([x-2*r,y-2*r,z-2*r]);
        translate([r,r,r])rotate([0,0,0])cylinder(z-2*r,r,r);
        translate([r,y-r,r])rotate([0,0,0])cylinder(z-2*r,r,r);
        translate([x-r,r,r])rotate([0,0,0])cylinder(z-2*r,r,r);
        translate([x-r,y-r,r])rotate([0,0,0])cylinder(z-2*r,r,r);
        
        translate([r,r,r])rotate([0,90,0])cylinder(x-2*r,r,r);
        translate([r,y-r,r])rotate([0,90,0])cylinder(x-2*r,r,r);
        translate([r,y-r,z-r])rotate([0,90,0])cylinder(x-2*r,r,r);
        translate([r,r,z-r])rotate([0,90,0])cylinder(x-2*r,r,r);
        
        translate([x-r,y-r,r])rotate([90,0,0])cylinder(y-2*r,r,r);
        translate([r,y-r,r])rotate([90,0,0])cylinder(y-2*r,r,r);
        translate([r,y-r,z-r])rotate([90,0,0])cylinder(y-2*r,r,r);
        translate([x-r,y-r,z-r])rotate([90,0,0])cylinder(y-2*r,r,r);
        
        translate([r,r,r])sphere(r = r);
        translate([x-r,r,r])sphere(r = r);
        translate([r,y-r,r])sphere(r = r);
        translate([x-r,y-r,r])sphere(r = r);
        
        translate([r,r,z-r])sphere(r = r);
        translate([x-r,r,z-r])sphere(r = r);
        translate([r,y-r,z-r])sphere(r = r);
        translate([x-r,y-r,z-r])sphere(r = r);
    }
}

module cylinder_r(h,r1,r2,r3,r4)
{
    hull()
    {
        translate([0,0,r3])cylinder(h-r3-r4,r1-r3,r2-r4);
        
        translate([0,0,r3])rotate_extrude(convexity = 10, $fn = 100)
            translate([r1, 0, 0])circle(r = r3, $fn = 100);
        
        translate([0,0,h-r4])rotate_extrude(convexity = 10, $fn = 100)
            translate([r2, 0, 0])circle(r = r4, $fn = 100);
    }
    
}

module rectTriangle(a,b,h)
{
linear_extrude(height = h, center = false, convexity = 10, twist = 0)
    polygon(points=[[0,0],[a,0],[0,b]]);   
}

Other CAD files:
3Dparts/STL/ACT_42BLF01_unified_V1_00.stl
3Dparts/STL/Hurst_unified_V1_00.stl
3Dparts/STL/Leadshine_EL5-M0400_HV_unified.stl
3Dparts/STL/Linix_unified_36ZWN24-30-34_bracket.stl
3Dparts/STL/ACT42BLF_blue_wedge_V1_00.stl
3Dparts/STL/Linix_unified_V1_00.stl
3Dparts/STL/ACT_23HS8430_unified_V1_00.stl
3Dparts/STL/MCLV2_TnutL01.stl
3Dparts/STL/PittmannN2344S017_unified_V1_00.stl
3Dparts/openSCAD/MCLV2_TnutL01.scad
3Dparts/openSCAD/MCLV2_TnutR01.scad
3Dparts/openSCAD/MCLV48_300_DIMhold.scad
3Dparts/STL/EBM_EC63.20_unified_V1_00.stl
3Dparts/STL/Elra_IPM110_HV_V1_00.stl
3Dparts/STL/MCLV48_300_DIMhold.stl
3Dparts/STL/MCLV48_300_TnutL01.stl
3Dparts/STL/Magtrol_TS105_01.stl
3Dparts/openSCAD/ACT42BLF_blue_wedge_V1_00.scad
3Dparts/openSCAD/ACT57BLF_blue_wedge_V1_00.scad
3Dparts/openSCAD/ACT_23HS8430_unified_V1_00.scad
3Dparts/openSCAD/ACT_42BLF01_unified_V1_00.scad
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

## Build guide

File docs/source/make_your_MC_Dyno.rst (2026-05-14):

Make Your MC-Dyno
===================

.. contents::
   :local:
   :depth: 2

1. Introduction
---------------

This page intent is to guide you on the creation of your first MC-Dyno project.
The MC-Dyno proposed here, is the cheapest and easiest assembly that can be done
to get a working MC-Dyno setup.
You can use this page as a guide even if you have a different motor, a different
controller board and/or different motor holders.

This page focuses on the dynamometer (dyno) side only. For the motor side, see
:doc:`Motor Side (Device Under Test) <Device_Under_Test>`.

.. tip::

   In some instances you will find **tip** blocks like these... in here you
   will find tips and tricks on how to improve or "hack" the MC-Dyno for your
   specific needs.

.. warning::

   Warning blocks are not decoration. If you ignore them, your MC-Dyno may
   respond with mysterious smoke. Read carefully--future-you will thank present-you.
   This warning has already saved several MC-Dyno projects...
   
All of the files and links that are required during the build are available here. 
These are mainly 3D models and source code.

Once you start following the different chapters, open the corresponding files and
links to have all of the required files handy.

The content might be updated over time. Legacy code will still be available in the **legacy** folder 
where the legacy files will be organized by date when they where out-commissioned.

1.1 Hardware
~~~~~~~~~~~~

.. admonition:: For a smooth MC-Dyno build...

   If you want the most up-to-date dyno-side hardware that is currently used in the majority
   of the **MC-Dyno projects** is: 

   - One `MCLV-48V-300W Development Board <https://www.microchip.com/en-us/development-tool/ev18h47a>`_ for the Dynamometer side (preferred, replaces MCLV-2)
   - One `AC300022 - 24V 3-PHASE BRUSHLESS DC MOTOR WITH ENCODER <https://www.microchip.com/en-us/development-tool/ac300022>`_ for the Dynamometer side
   - If you already have a `MCLV-2 Development Board <https://www.microchip.com/en-us/development-tool/dm330021-2>`_, you can use it for the Dynamometer side instead.
   - If you use the `MCLV-2 Development Board <https://www.microchip.com/en-us/development-tool/dm330021-2>`_ for communicating with the PC, reading data and controlling the dynamometer, an USB to RS232 board is suggested, this is the one used in the majority of the MC-Dyno Projects: `MCP2200 USB TO RS232 DEMO BOARD <https://www.microchip.com/en-us/development-tool/mcp2200ev-vcp>`_

**Required hardware (Dyno side)**

- One `MCLV-48V-300W Development Board <https://www.microchip.com/en-us/development-tool/ev18h47a>`_ (preferred) or one `MCLV-2 Development Board <https://www.microchip.com/en-us/development-tool/dm330021-2>`_ for the dynamometer controller.
- One `AC300022 - 24V 3-PHASE BRUSHLESS DC MOTOR WITH ENCODER <https://www.microchip.com/en-us/development-tool/ac300022>`_ for the dynamometer side. 
- One `3A 24V Power Supply <https://www.microchipdirect.com/dev-tools/AC002013>`_
- Flexible aluminum jaw shaft coupling (if the above suggested motors are used, then 8mm bore should be selected).
- Eight M4 x 10 mm hex-socket screws
- 3D printed brackets, which can be found in the `3Dparts <https://github.com/ImpressiveTaste/Dyno-MCHP-Repository-WIP/tree/main/3Dparts>`_ folder (OpenSCAD + STL).
- Wood mounting base or 4 (20x20) T-slot aluminum profiles, minimum length 500 mm
- For T-slot mounting Eight M5 socket-head cap screws (M5 SHCS) - 16 mm
- For T-slot mounting Eight M5 T-slot nuts
- Windows PC running Windows 10.

**Alternative Hardware (Dyno side)** 

- For High Voltage Motor Testing - One `MCHV-230V-1.5kW Development Board <https://www.microchip.com/en-us/development-tool/ev78u65a>`_ for the dynamometer side.
- `MCLV-2 Development Board <https://www.microchip.com/en-us/development-tool/dm330021-2>`_ can be used instead of the MCLV-48V-300W for the dynamometer side, performance is very similar. 
- An alternative motor that can be used for the Dynamometer side is the `ACT57BLF02 Motor <https://www.act-motor.com/brushless-dc-motor-57blf-product/>`_, actually any motor that has a QEI/ABZ Encoder can be used by then doing the correct modificaiton to the code to support it.

1.2 Software needed
~~~~~~~~~~~~~~~~~~~

- Scilab 6.1.1 (installation directory: https://www.scilab.org/download/previous-versions); newer versions will not work. (Scilab 2023.1.0 should also work).
- X2C 6.4 (Installation tutorial: https://www.youtube.com/watch?v=H_EVY1D95eY)  
- MPLAB X IDE and MPLAB X IPE (installation: https://www.microchip.com/en-us/tools-resources/develop/mplab-x-ide)
- XC-DSC 3.21, which you can install during process of installation of MPLAB X
- MPLAB XC32 5.00 , which you can install during process of installation of MPLAB X

2. Assembling the hardware
--------------------------

In this section the steps to build the MC-Dyno dynamometer side will be described. 
This is the **easiest possible MC-Dyno** you can make, but as you saw in the home page, you are free to play around
and make the MC-Dyno that best suits your needs.

Before starting this guide, navigate to the file section `3Dparts <https://github.com/ImpressiveTaste/Dyno-MCHP-Repository-WIP/tree/main/3Dparts>`_ 
and **3D print the motor mounts** for the dynamometer side motor used. For the dynamometer side, use 
`Hurst_blue_wedge_V1_00.stl <https://github.com/ImpressiveTaste/Dyno-MCHP-Repository-WIP/blob/main/3Dparts/STL/Hurst_blue_wedge_V1_00.stl>`_. 
Print one bracket for the dynamometer motor. If you are also building the DUT side, the ACT57BLF bracket is listed on the
:doc:`Motor Side (Device Under Test) <Device_Under_Test>` page.
There are two bracket sizes available: small for portable demonstrators (blue wedge) and standard 
size (unified). Before printing, decide the motor brackets versions that matches best your setup.
You can also find the **openSCAD files for the brackets**
in there, so if you would like to **modify** this model to fit a **different motor**, you're welcome to do so. 

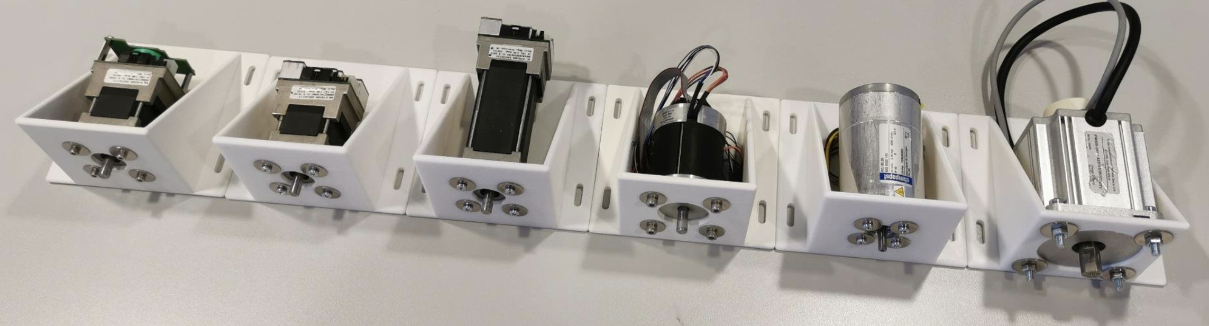
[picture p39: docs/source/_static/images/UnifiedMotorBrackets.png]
Unified Motor Brackets


   Some of the Many Unified Motor Brackets

You can print this model in PLA or PETG and make sure to set the infill to 100%. 
You don't need to enable any supports.

2.1 Step 1: Mount Dynamometer Motor to 3D printed braket, align and fix
~~~~~~~~~~~~~~~~~~~~~~~~~~~~~~~~~~~~~~~~~~~~~~~~~~~~~~~~~~~~~~~~~~~~~~~

As a first step, mount the dynamometer motor in the **mounting bracket** that you have 3D printed. 

After that, fix the motor bracket to the T-Slot or your base support. 

If you are using different motors be sure to make the brackets in such a way that the motor
shafts are aligned. This is very important. Align the dyno motor shaft with the DUT motor shaft
using the shaft coupler to help you align them. 

Fix everything by tightening the different screws. If the shaft coupler spins freely, then the "hand alignment process" was
correct, if you see wiggle or that the shaft requires different forces in different positions to rotate, that might mean that
the motor shafts are not completely aligned. If that happens please untighten, move the brackets as needed and tighten
the screws needed to guarantee the best alignment possible. 

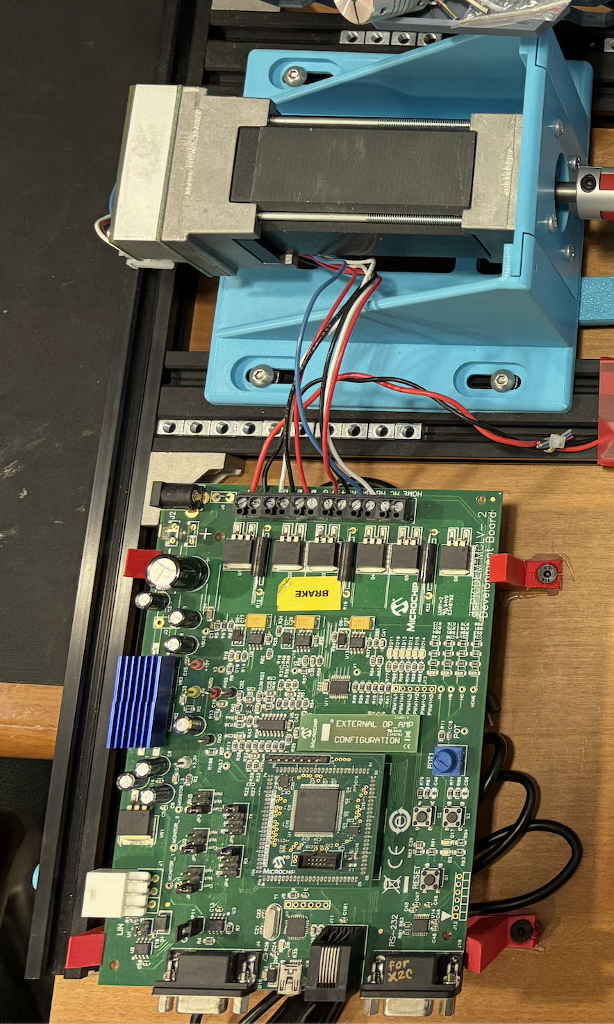
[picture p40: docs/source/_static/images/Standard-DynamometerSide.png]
Standard Dynamometer Side


   Standard Dynamometer Side

.. tip::

   The shaft coupler can handle some small misalignment but will add unnecessary force to the Motor
   shafts, making the control not reliable, for this reason try to ensure shaft alignment between motors.

2.2 Setup Boards and wire them to the motors
~~~~~~~~~~~~~~~~~~~~~~~~~~~~~~~~~~~~~~~~~~~~

.. warning::

   To avoid the Dynamometer to destroy itself, it's **mandatory** to have a power sink 
   for the DC-link voltage. Best way is to **connect both DC link boards together**. 
   **If you are doing a default MC-Dyno configuration, only use one power supply and then connect the two boards
   together to share the power from the power supply, this will allow for sink of exceeding power in the motor that
   requires energy and keep the DC-Link voltage regulated.**

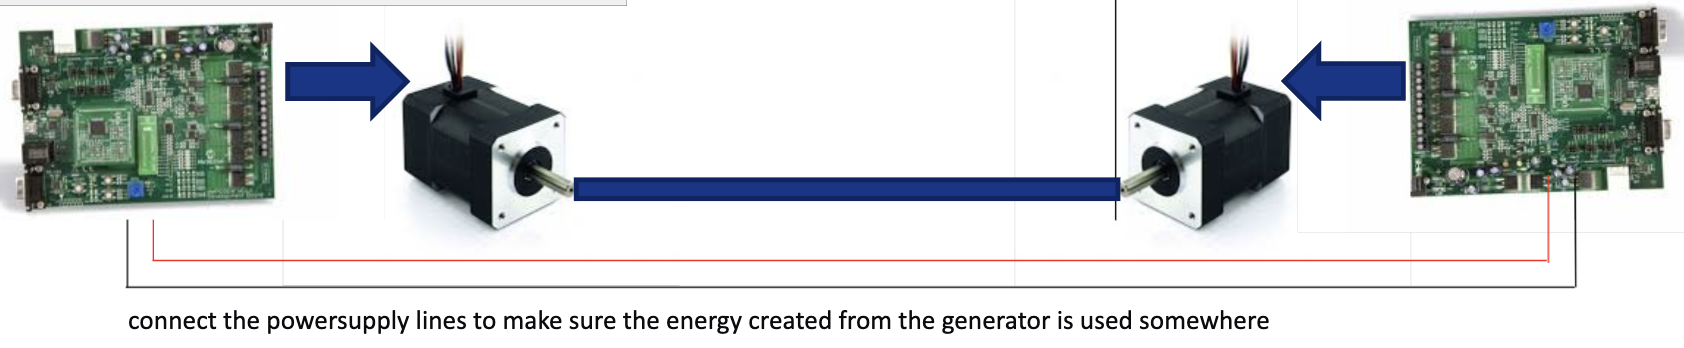
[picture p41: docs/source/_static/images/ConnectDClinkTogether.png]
DC Link connection requirements


   To avoid the Dynamometer to destroy itself, it's mandatory to have a power sink for the DC-link voltage. Best way is to connect both DC link boards together.

**2.2.1 Wiring the Dynamometer side**

For wiring the Hurst Motor, use the standard connectors provided in the box. The cables you will want are shown in the picture below. 

Feel free to cut the not used cables like in the picture.

.. list-table::
   :widths: 50 50
   :align: center

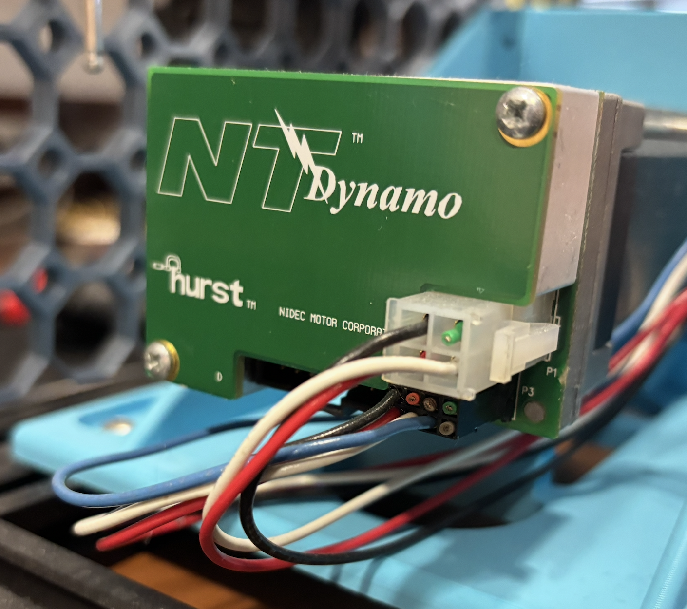
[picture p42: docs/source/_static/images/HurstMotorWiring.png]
HurstMotorWiring
   * - 

          Hurst Motor Wiring
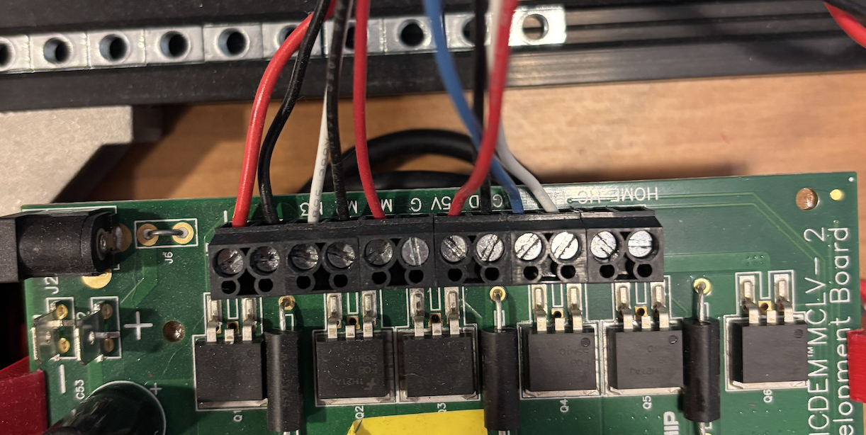
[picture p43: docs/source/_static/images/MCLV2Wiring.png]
MCLV-2 wiring
     - 

          MCLV-2 wiring

**2.2.2 Configure MCLV-48V-300W (Preferred)**

The MCLV-48V-300W is the current dyno-side board and replaces the MCLV-2 for new builds.
Use it if you are starting a new dyno build. If you already have an MCLV-2 board, use that one instead
(see the next section).

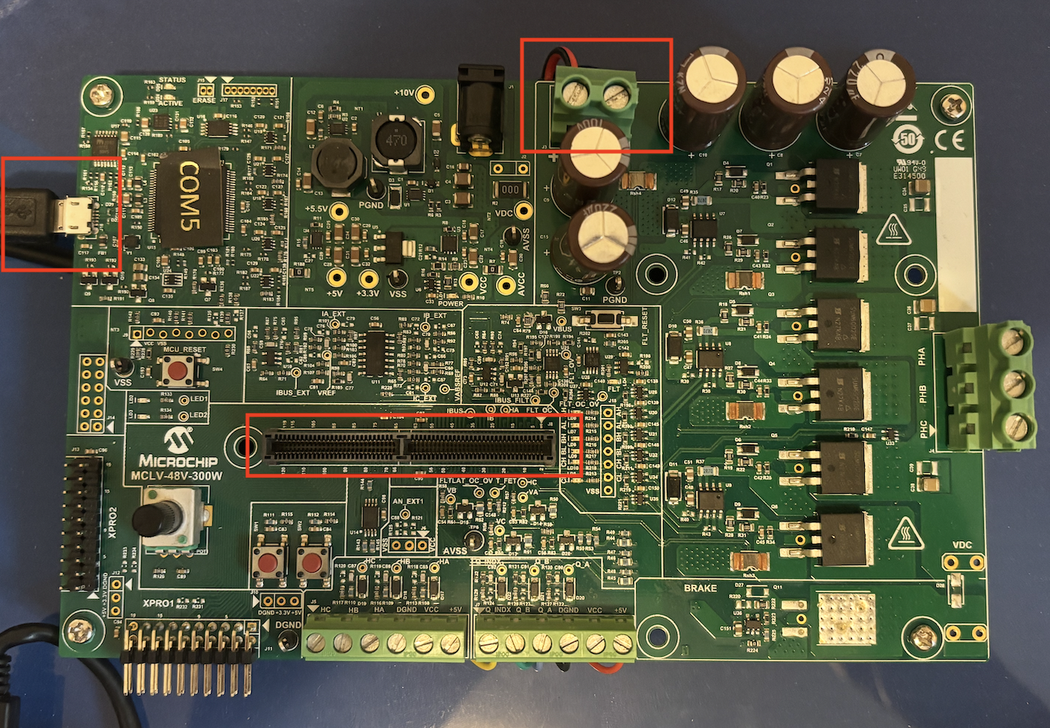
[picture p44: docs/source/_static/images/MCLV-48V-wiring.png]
MCLV-48V-300W board configuration


   MCLV-48V-300W board configuration

**2.2.3 Configure MCLV-2 (Legacy)**

For the MCLV-2 you will need the `ATSAM54P20A External OpAmp PIM board <https://www.microchip.com/en-us/development-tool/ma320207>`_.
Other than that you will need to configure the board like shown in the picture below (make sure all jumpers in your board are placed in the same way as in the reference picture):

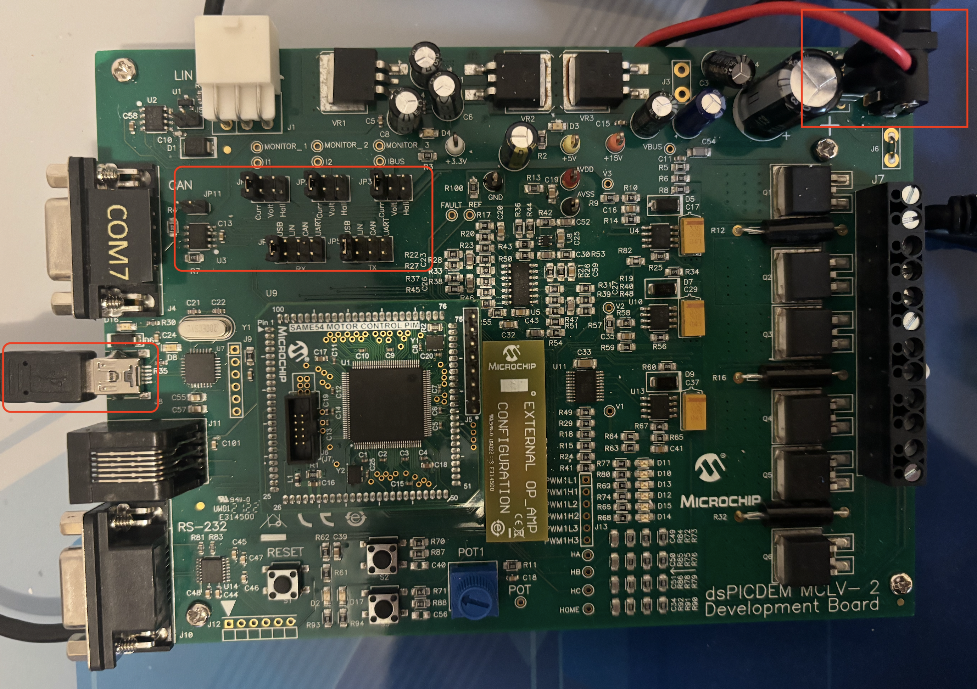
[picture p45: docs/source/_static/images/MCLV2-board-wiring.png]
MCLV-2 board configuration


   MCLV-2 board configuration

In this case, we are connecting the 24Volt power source to this board, and then going out with two cables (positive and negative) from the MCLV-2 board to the DUT board
to share the DC-Link and guaranteeing not being able to dissipate the energy created while braking the motor. The same done here, **has to be done** also with the MCLV-48V-300W board.

3. Load the software
--------------------

Dyno-side firmware is provided for both boards in this repository. You can download
pre-compiled HEX files for standalone operation, or the full MPLAB X project if you
want to modify the code.

**MCLV-48V-300W (Preferred for new builds)**

- :download:`Download HEX file <https://github.com/ImpressiveTaste/Dyno-MCHP-Repository-WIP/raw/main/MCDyno/mc_foc_dyno_same54_mclv48v300w/doc/standalone/MC_FOC_DYNO_SAME54_MCLV48V300W.X.production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>`
- :download:`Download full project (ZIP) <https://github.com/ImpressiveTaste/Dyno-MCHP-Repository-WIP/raw/main/MCDyno/mc_foc_dyno_same54_mclv48v300w/doc/standalone/mc_foc_dyno_same54_mclv48v300w.zip>`
- Project folder: ``MCDyno/mc_foc_dyno_same54_mclv48v300w``

**MCLV-2 (Legacy, use if you already have this board)**

- Project folder: ``MCDyno/mc_foc_dyno_same54_mclv2``
- Standalone files: ``MCDyno/mc_foc_dyno_same54_mclv2/doc/standalone/``

3.1 Programming the firmware
~~~~~~~~~~~~~~~~~~~~~~~~~~~~

To program the HEX file onto your board:

1. Connect the board to your PC via USB (the MCLV-48V-300W has an on-board PKOB4 programmer, no external programmer needed)
2. Open **MPLAB X IPE** (Integrated Programming Environment)
3. Select the device: **ATSAME54P20A**
4. Load the HEX file you downloaded
5. Click **Program**
6. Reset the board

.. note::

   If using an MCLV-2, you will need an external programmer (ICD4, PICkit4, or SNAP) connected to the board.

.. tip::

   If you want to modify the firmware, download the full project ZIP, extract it,
   and open the ``.X`` project folder in MPLAB X IDE. You will need XC32 compiler
   installed to rebuild the project

4. Run the MC-Dyno - step-by-step
-----------------------------------

After both sides are assembled and programmed, follow the runtime steps in :doc:`usage`.

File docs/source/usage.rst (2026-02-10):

Procedure for using the MC-Dyno:
================================

.. contents::
   :local:
   :depth: 2

1. Purpose
----------

Step-by-step operator checklist to prepare, run, present, and safely shut down the
DUT + MC-Dyno. 

2. Checklist before starting up the MC-Dyno
-------------------------------------------

**Hardware**

- PC, power, keyboard/mouse.
- Two MCLV boards mounted with printed brackets (use the STL brackets), motor and dyno physically connected.
- **Single DC power supply connected to both boards**.
- USB cable connected to the two boards for getting data in and out.

**Software**

- Scilab installed (tested version is OK; recommended 2024.1.0 but 6.1.1 works).
- X2C (X2C blocks in Scilab) installed and visible in Scilab on startup.
- pyX2Cscope / X2C-scope app (standalone) or web-interface app to be used for the DUT side. Can be downlaoded here: https://github.com/X2Cscope/pyx2cscope/releases

3. Power / Safety (Must-Read)
-----------------------------

.. warning::

   - **Use one DC power supply only**. Do NOT power the motor board and dyno board with separate supplies.
     Link + / - terminals so both boards share the same supply.
   - Fault / safety LED: All MCLV-48V-300W boards have a hardware safety switch ("fault" / overcurrent protection).
     If that LED is ON the PWMs are disconnected (no power to gate drivers). Press the small fault-reset button
     (one press) to clear and re-enable the power stage.
   - Never press mechanical switches on the Dyno Side while the motor is running. If behavior becomes uncontrollable:
     STOP the DUT side (switch1), reset fault if lights up, then restart.

4. Start-up Procedure (Order Is Important)
------------------------------------------

#. Turn on power only after cabling is verified.
#. Start Scilab.
#. Confirm X2C is loaded in Scilab (X2C menu appears). If X2C does not initialize on Scilab startup,
   run the X2C init script.
#. In the Scilab file browser, right-click ``init_project.sce`` and Execute.
   Wait for XCOS to open with the MC-Dyno model.
#. Double-click "Transform model" to generate the runtime model for the communicator.
#. Leave the Communicator window open. Check the communicator window title: model name should appear
   (for example, ``MC_FOC_Dyno``). If it matches, proceed.
#. Open Windows Device Manager -> Ports to see COM assignments.
   If unsure which COM is which, unplug the motor-side USB to identify dyno vs motor port.
   Typical mapping used in testing: Dyno = ``COM5``, Motor = ``COM4`` -- verify locally.
#. In the Scilab model: double-click Start Communicator -> Setup -> select the COM port and refresh ports.
   Connect. If COM error appears, choose the other COM and try again.
#. In the Scilab model: set torque mode (double-click torque-mode selector). 
   IN here you can choose different torque mdoes, such as trapezoidal dynamic loads (safer for long running) or constant torque for a simple demo. For a quick demo:
   use constant torque, then switch to trapezoidal or unbalanced load to analyze effects.

6. X2C-scope / pyX2Cscope Usage (Data and Visualization)
--------------------------------------------------------

#. Launch the pyX2Cscope / X2C-scope app (standalone) or open the web-interface app. Can be downlaoded here: https://github.com/X2Cscope/pyx2cscope/releases
#. Select the ELF file associated to the code that is running in the DUT (this lets the scope map variable names to MCU memory). You can find the elf file in *production/dist*, inside the project folder. 
#. Select the port (auto-connect tries COM ports; if it chooses wrong, manually select the COM).
#. Add variables to view (if you are running an MCAF based prject):

   - ``motor.IDQ.Q`` (quadrature current -> torque)
   - ``motor.IDQ.D`` (direct current)
   - ``IABC.IA`` (phase current IA)
   - ``motor.OmegaElectrical`` (or ``OmegaMechanical`` / velocity scaled to RPM)

#. If you are running fixed point code copy gain values into each variable's "gain" field (this is optional but usefull since numeric changes are helpful to show RPM/current in real units).
#. Sample time factor:

   - For slow trapezoidal loads and long runs: use Sample Time Factor ~ 50
   - For dynamic/transient viewing of current/IDQ: reduce factor (5 or 1) for higher time resolution
   - If scope is noisy, increase factor (longer time window) or pick appropriate variables

#. Press SAMPLE to display live traces.

7. Shutdown Procedure (In Order)
--------------------------------

#. Stop motor (switch1).
#. In X2C scope: press STOP, disconnect.
#. In Scilab: stop communicator, close model windows. When prompted to save, select DO NOT SAVE
   (prevents accidental model changes).
#. Close Scilab.
#. Power down boards.

8. Common Problems and Fixes
----------------------------

- **Two separate power supplies:** do NOT use two supplies. Link green terminals and use single supply --
  otherwise regenerative braking can raise voltage and damage boards.
- **Motor cogging / erratic below ~50 RPM:** encoder resolution limits low-speed smoothness. Keep demo speeds
  above ~50-100 RPM or use 0-speed torque cautiously. If controller locks / spins fast unexpectedly: STOP motor,
  press switch1 to reset, restart.
- **Scope shows unexpected values or no values:** verify ELF-file loaded in scope, correct COM port, and that the
  Communicator model matches the model name in the communicator window.

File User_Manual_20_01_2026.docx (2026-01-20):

# User’s Guide: Blue Wedge

Last Updated 20/01/2026

## Software:

1. Open Scilab:
  a. Go to ...\src\config\default\X2CCode\X2CModel\
  b. Right click on initProject.sce and select execute in scilab. the model should open.

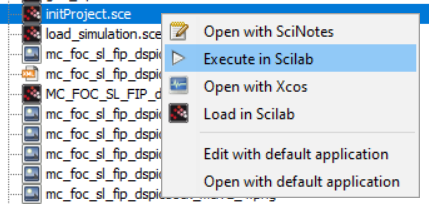
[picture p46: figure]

  d. Double Click on Start Communicator.
  f. If the connection is established in X2C, then double click on transform model and push to communicator, if the model is successfully transformed, there should be name of the model on the X2C window.
  a. If the connection is not established, check the serial port setting (COM-Port 7 should be selected) (appropriate Com-port is selected) on X2C as well as the physical connection on hardware and try to connect again on X2C.
  b. From scilab model, torque profile could be changed for demonstration.
3. Establish the physical connection Navigate to the src folder and execute the relay_process_start.cmd script to establish a physical connection between the edge device and SA Studio.!!!
4. Open Visual studio code:
  a. click on stream analyze extension.

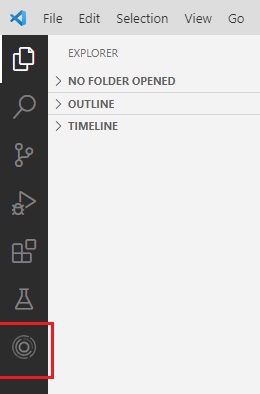
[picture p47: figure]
SA Engine icon

  b. Open the command line by ctrl + shift + p, and connect the edge to local federation by command SA Engine: Connect to federation
  d. Create an interactive osql window by running SA Engine: Create ab interactive OSQL window as shown below.
  f. Go to …\stream_analyze\apps\ and open Microchip-simple-demo.osql in VS code.
  g. Place the cursor online start_nameserver(“ns”);
  i. Press Shift + Enter, this will execute the command and if everything goes well, you will see, as shown below:
  k. Setting is done, to verify, run the commad edge_cq("edge1","1+1");
  l. Simply by placing the cursor on the command and press Shift + Enter to execute. As output you should see “2”
  m. Start the final command, which will start the line graph 📈. (Shift + Enter on the command.)

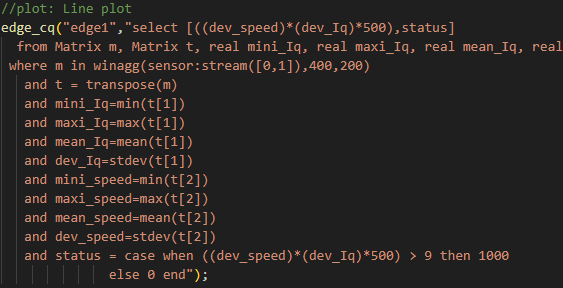
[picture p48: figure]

## Hardware:

1. Connect the mikroBUS and connect the power cable as shown in the picture below and please remove it before leaving or packing the demo:

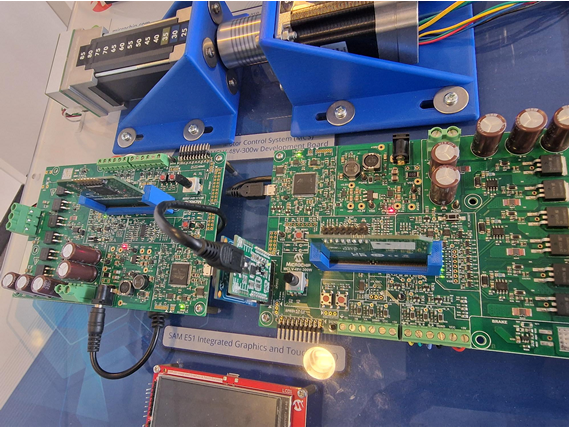
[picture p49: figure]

2. Once all the software part is done, press the S2 Switch on the motor side to start the motor. This should turn on the PWM LEDs on the motor side and wait untill the motor starts to spin as shown in picture above.
3. In the model go to Dyno as shown in image below:

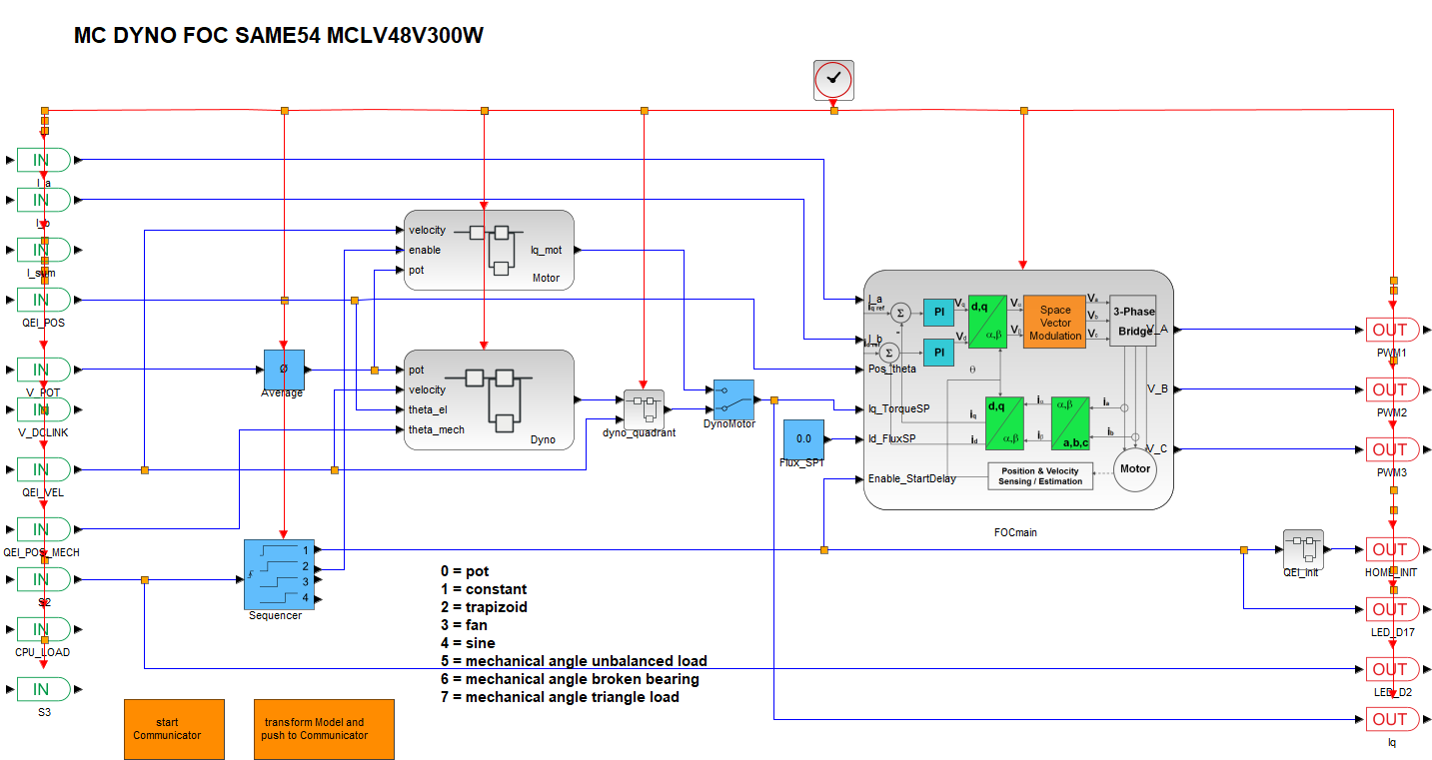
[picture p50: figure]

4. Double click on torque mode and select the torque profile with the description:

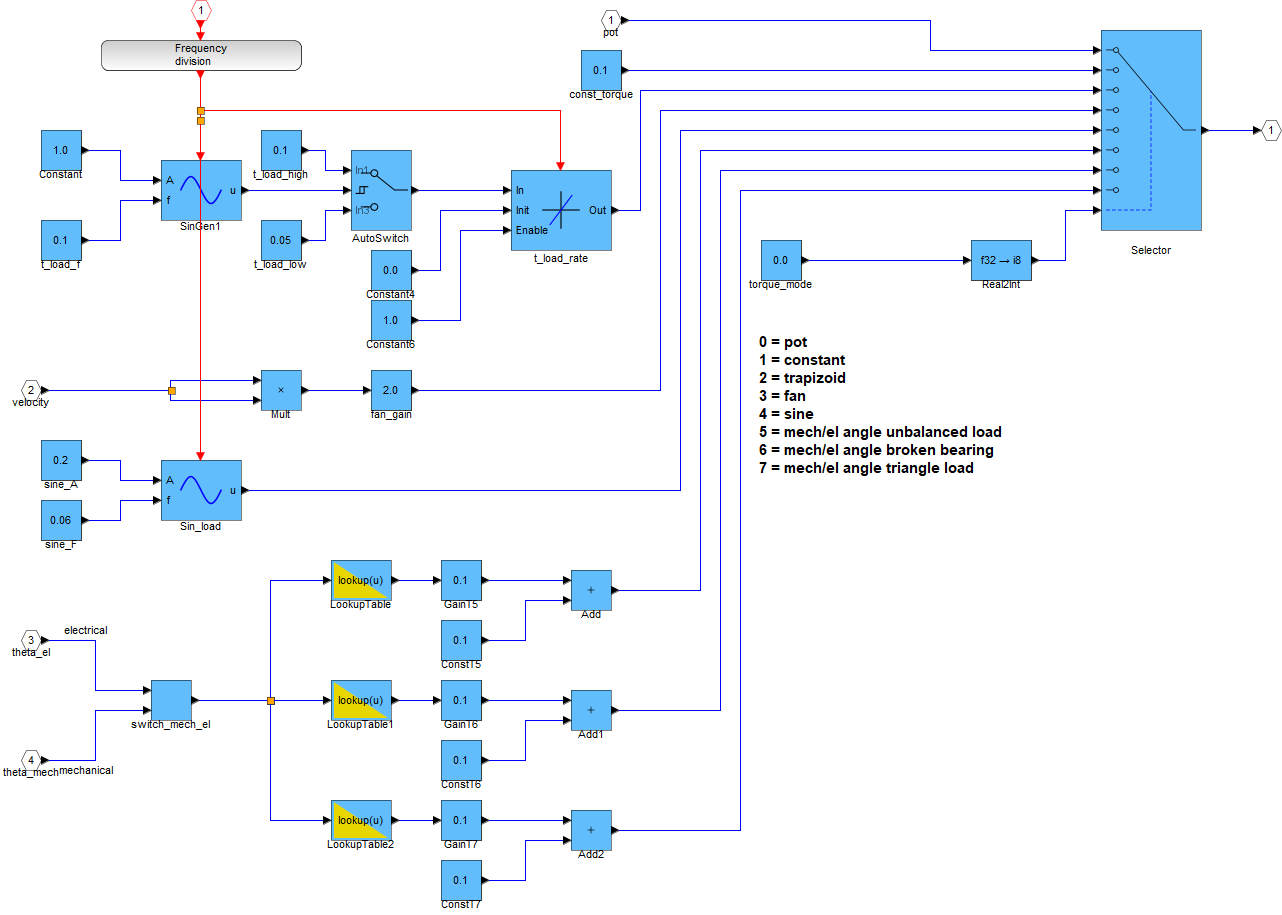
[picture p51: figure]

5. To demonstrate Predictive maintenance, select either: 0 Constant torque or 5 Mechanical unbalanced load and press enter to set the value in run time mode.

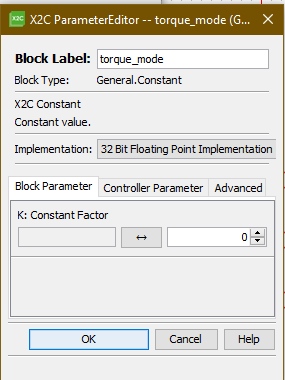
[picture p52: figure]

## Firmware Settings:

### 1. Rapid Prototyping model in Scilab based on dsPIC33CK on motor side:

1. Select project mc_foc_sl_fip_dspic33ck_mclv48v300w as main project and open MCC
2. once MCC is open, Go to X2C from project resources, as shown in the image below.

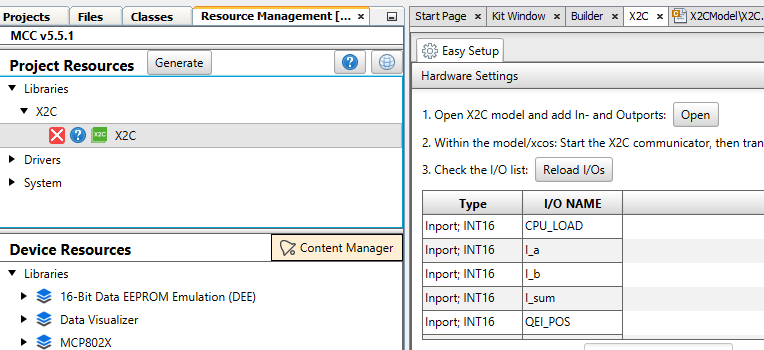
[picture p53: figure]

3. Press the Open button (Only once !!)

4. This will open Scilab and initiate the Model

5. In the main model, Double Click on Start Communicator.

6. If the connection is established in X2C, then double click on transform model and push to communicator, if the model is successfully transformed, there should be name of the model on the X2C window.

6. If the connection is not established, check the serial port setting (COM-Port 5 should be selected) (appropriate Com-port is selected) on X2C as well as the physical connection on hardware and try to connect again on X2C.

To restore Wedge: In case things are not working as mentioned earlier, Please restore the Bluewedge.

It sound hard but its very simple

This is used by the Windows demo PC ("wedge") to restore the Blue Wedge firmware/demo workspace if needed. The restore is a simple batch script that unzips RestoreWedge/BlueWedge_firmware.zip to the demo user's Desktop. The zip holds the firmware projects, models, and Stream Analyze assets used by the demo.

navigate yourself to desktop and look for a batch file called RestoreWedge-Shortcut.

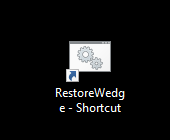
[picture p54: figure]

Double click on it, it will start the Restoring process….

Do not close this window until you see the message Done Restoring Blue Wedge.

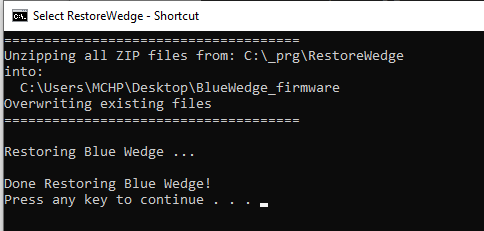
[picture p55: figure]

How RestoreWedge works in a nutshell

1. SOURCE_DIR is C:\_prg\RestoreWedge and DEST_DIR is C:\Users\MCHP\Desktop\BlueWedge_firmware.
2. Creates DEST_DIR if it does not exist.
3. For each *.zip in SOURCE_DIR, runs PowerShell: Expand-Archive -LiteralPath <zip> -DestinationPath <DEST_DIR> -Force
4. Pauses so the operator can see the "Done Restoring Blue Wedge!" message.

Override behavior and result

- Destination is C:\Users\MCHP\Desktop\BlueWedge_firmware.
- Expand-Archive -Force overwrites existing files with the same path.
- Files already in the destination that are not in the zip are not deleted.

What the restore payload contains

RestoreWedge/BlueWedge_firmware.zip expands into C:\Users\MCHP\Desktop\BlueWedge_firmware and includes:

- .git/: git metadata from the captured snapshot (not required for the demo).
- .~lock.User_Manual.docx#: temporary lock file from LibreOffice; safe to ignore.
- 33ak_MCLV48V300W_FOC_PLL/: dsPIC33AK FOC + PLL motor control project; docs in docs/README.pdf.
- AIoT_mclv48V300W_same54/: AIoT firmware for SAME54; includes libs and predictive_maintenance_mc with relay_process_start.cmd and connect.osql.
- AIoT_mclv48V300W_same54.zip: zipped snapshot of the AIoT project.
- MC_FOC_DYNO_SAMe54_MCLV48V300W/: SAM E54 motor control dyno project; includes X2C Scilab model initProject.sce.
- Predictiv_maintenance_dsPIC33CK/: master thesis artifacts for dsPIC33CK anomaly detection and knowledge packs.
- README.md: minimal readme inside the payload.
- RestoreWedge.bat: older template pointing to C:\Users\MCHP\Downloads; not used for wedge restore.
- SAME54-48V300W-Qspin-FOC/: QSpin FOC project for SAME54 (nested .X and src).
- anomaly-detection-mclv-48v-300w.X/: MPLAB X project for anomaly detection on dsPIC33CK/MCLV-48V-300W.
- gfx_apps_sam_d5x_e5x/: empty placeholder folder (nested empty folder).
- masterthesis-add_newApproach@c295d48f2ed.zip: zipped research snapshot.
- mc_foc_sl_fip_dspic33ck_mclv48v300w_Melody/: dsPIC33CK motor control project generated via MCC/X2C; see its readme.md for tools/hardware.
- motorBench_ZSMT_dspic33ck_act57blf_48V300W.X/: motor bench project and configs for the ACT motor.
- motorbench_FOC_PLL_dsPIC33CK_MCLV_48_300_ACT57BLF02.X/: motor bench FOC PLL project (nested .X).
- predictive_maintenance_mclv48v300w_same54/: predictive maintenance demo; OSQL scripts, relay_process_start.cmd, connect.osql, and an MPLAB project.
- predictive_maintenance_mclv48v300w_same54_PKOB_Serial.zip: zipped snapshot of a predictive maintenance variant.
- src/: standalone Harmony source tree for ATSAME54P20A (QSpin + X2Cscope), used as a base firmware project.
- stream_analyze-feat-MCLV-48v-300w_longhurst/: Harmony Stream Analyze repo with docs and apps (including Microchip-simple-demo.osql).

Reproduce this setup on another PC

1. Create the folder layout:
  - C:\_prg\RestoreWedge (or edit the batch file if you must use a different path).
2. Copy the payload and script from this repo:
  - RestoreWedge/BlueWedge_firmware.zip -> C:\_prg\RestoreWedge\BlueWedge_firmware.zip
  - RestoreWedge/RestoreWedge.bat -> C:\_prg\RestoreWedge\RestoreWedge.bat
3. If the new PC has a different Windows user, update DEST_DIR in RestoreWedge.bat (default is C:\Users\MCHP\Desktop\BlueWedge_firmware). You can use TextEdit or VScode for that.
4. Create a desktop shortcut that points to C:\_prg\RestoreWedge\RestoreWedge.bat and name it RestoreWedge-Shortcut.
5. Install software dependencies: Scilab, X2C, MPLAB….
6. Restore once and verify:
  - Run the batch file.
  - Try the files

Updating the restore image

1. On a working wedge, zip the full C:\Users\MCHP\Desktop\BlueWedge_firmware folder.
2. Replace C:\_prg\RestoreWedge\BlueWedge_firmware.zip with the new zip.
3. Re-run RestoreWedge.bat to validate.

Troubleshooting

- If restore fails, check PowerShell availability and permissions for C:\_prg and the Desktop destination.
- If SA Engine will not connect, update COM port in connect.osql and ensure the USB serial device is present.
- If X2C will not connect, verify the COM port and motor-control USB connection.

RestoreWedge.bat script:

@echo off

REM ====================================

REM Define your source and destination

REM paths here. Change them as needed.

REM ====================================

SET "SOURCE_DIR=C:\Users\MCHP\Downloads\zip"

SET "DEST_DIR=C:\Users\MCHP\Downloads\"

REM ----------------------------------------------------

REM Unzips all zip files from %SOURCE_DIR%

REM into %DEST_DIR%, overwriting any existing files.

REM ----------------------------------------------------

echo =====================================

echo Unzipping all ZIP files from:

echo %SOURCE_DIR%

echo into:

echo %DEST_DIR%

echo Overwriting existing files

echo =====================================

echo.

REM 1) Create the destination folder if it doesn't exist

if not exist "%DEST_DIR%" (

echo Creating folder: %DEST_DIR%

mkdir "%DEST_DIR%"

echo.

)

REM 2) Loop through each ZIP file in the source directory

for %%z in ("%SOURCE_DIR%\*.zip") do (

echo Extracting %%~nz.zip ...

powershell.exe -NoProfile -Command ^

"Expand-Archive -LiteralPath '%%~fz' -DestinationPath '%DEST_DIR%' -Force"

)

echo.

echo Done extracting all ZIP files!

pause

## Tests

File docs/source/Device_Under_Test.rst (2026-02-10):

Motor Side (Device Under Test)
==============================

This page covers the motor-side (DUT) hardware, assembly, and control firmware.
For the dynamometer side, see :doc:`Make Your MC-Dyno <make_your_MC_Dyno>`.

.. contents::
   :local:
   :depth: 2

1. Hardware
-----------

.. admonition:: For a smooth MC-Dyno build...

   If you want the most up-to-date DUT-side hardware that is currently used in the majority
   of the MC-Dyno projects is:

   - One `MCLV-48V-300W Development Board <https://www.microchip.com/en-us/development-tool/ev18h47a>`_ for the Device-Under-Test side
   - One `ACT57BLF02 Motor <https://www.act-motor.com/brushless-dc-motor-57blf-product/>`_ for the Device-Under-Test side

**Required hardware (DUT side)**

- One `MCLV-48V-300W Development Board <https://www.microchip.com/en-us/development-tool/ev18h47a>`_ for the DUT side.
- One `ACT57BLF02 Motor <https://www.act-motor.com/brushless-dc-motor-57blf-product/>`_ for the DUT side.
- One `3A 24V Power Supply <https://www.microchipdirect.com/dev-tools/AC002013>`_ (shared with the dyno side).
- Flexible aluminum jaw shaft coupling (if the above suggested motors are used, then 8mm bore should be selected).
- Eight M4 x 10 mm hex-socket screws
- 3D printed brackets, which can be found in the `3Dparts <https://github.com/ImpressiveTaste/Dyno-MCHP-Repository-WIP/tree/main/3Dparts>`_ folder (OpenSCAD + STL).
- Wood mounting base or 4 (20x20) T-slot aluminum profiles, minimum length 500 mm
- For T-slot mounting Eight M5 socket-head cap screws (M5 SHCS) - 16 mm
- For T-slot mounting Eight M5 T-slot nuts
- Windows PC running Windows 10.

**Alternative Hardware (DUT side)**

- For High Voltage Motor Testing - One `MCHV-230V-1.5kW Development Board <https://www.microchip.com/en-us/development-tool/ev78u65a>`_ for the DUT side.
- An alternative motor that can be used for the DUT side is the `AC300022 - 24V 3-PHASE BRUSHLESS DC MOTOR WITH ENCODER <https://www.microchip.com/en-us/development-tool/ac300022>`_.

2. Assembling the hardware
--------------------------

In this section the steps to build the MC-Dyno motor side (DUT) will be described.

Before starting this guide, navigate to the file section `3Dparts <https://github.com/ImpressiveTaste/Dyno-MCHP-Repository-WIP/tree/main/3Dparts>`_
and **3D print the motor mounts** for the DUT motor used. For the DUT side, use
`ACT57BLF_blue_wedge_V1_00.stl <https://github.com/ImpressiveTaste/Dyno-MCHP-Repository-WIP/blob/main/3Dparts/STL/ACT57BLF_blue_wedge_V1_00.stl>`_.
Print one bracket for the DUT motor.
There are two bracket sizes available: small for portable demonstrators (blue wedge) and standard
size (unified). Before printing, decide the motor brackets versions that matches best your setup.
You can also find the **openSCAD files for the brackets**
in there, so if you would like to **modify** this model to fit a **different motor**, you're welcome to do so.

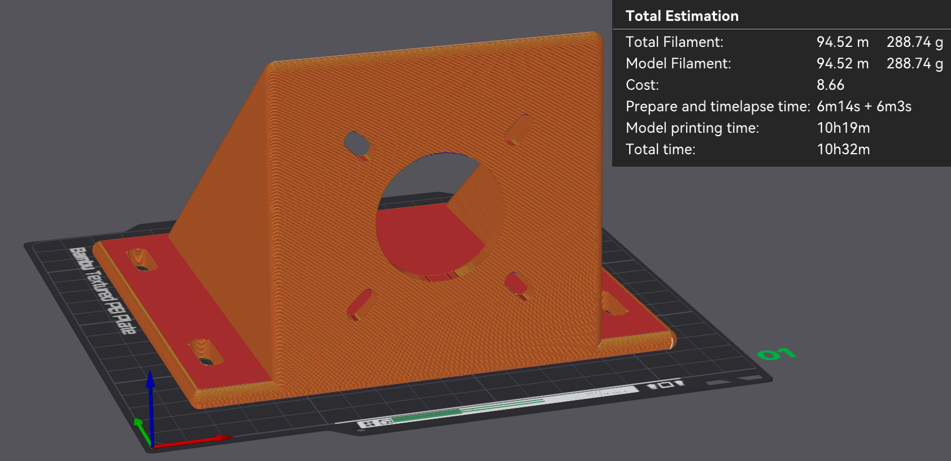
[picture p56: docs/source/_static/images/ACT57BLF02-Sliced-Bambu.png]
ACT57BLF02 bracket slicing preview


   ACT57BLF02 bracket -- slicing preview (PLA, 100% infill).

2.1 Step 1: Mount DUT Motor to 3D printed braket, align and fix
~~~~~~~~~~~~~~~~~~~~~~~~~~~~~~~~~~~~~~~~~~~~~~~~~~~~~~~~~~~~~~~

As a first step, mount the DUT motor in the **mounting bracket** that you have 3D printed.

After that, fix the motor bracket to the T-Slot or your base support.

If you are using different motors be sure to make the brackets in such a way that the motor
shafts are aligned. This is very important. Align the DUT motor shaft with the dyno motor shaft
using the shaft coupler to help you align them.

Fix everything by tightening the different screws. If the shaft coupler spins freely, then the "hand alignment process" was
correct, if you see wiggle or that the shaft requires different forces in different positions to rotate, that might mean that
the motor shafts are not completely aligned. If that happens please untighten, move the brackets as needed and tighten
the screws needed to guarantee the best alignment possible.

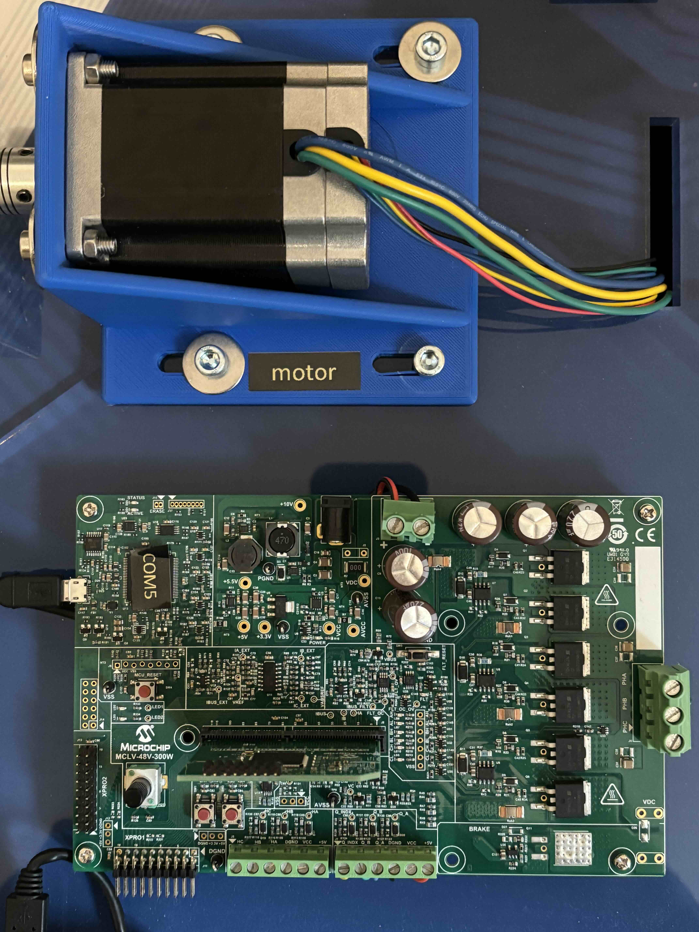
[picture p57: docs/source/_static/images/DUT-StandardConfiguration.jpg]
DUT Standard Configuration


   DUT Standard Configuration

.. tip::

   The shaft coupler can handle some small misalignment but will add unnecessary force to the Motor
   shafts, making the control not reliable, for this reason try to ensure shaft alignment between motors.

2.2 Setup Boards and wire them to the motor
~~~~~~~~~~~~~~~~~~~~~~~~~~~~~~~~~~~~~~~~~~~

**2.2.1 Wiring the Device-Under-Test side**

For Wiring the ACT motor to the MCLV-48V-300W board follow the image below as reference.

For phase A connect the yelow wire, for phase B connect the green wire and for phase C connect the BLU wire

.. list-table::
   :widths: 50 50
   :align: center

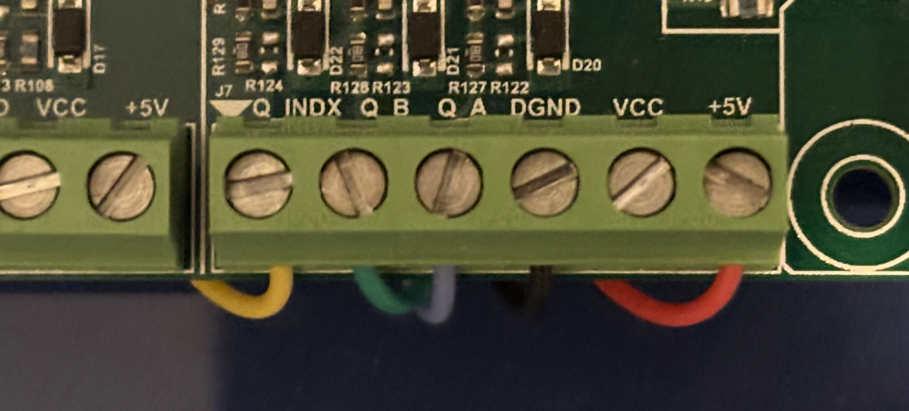
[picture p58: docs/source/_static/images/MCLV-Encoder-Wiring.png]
HurstMotorWiring
   * - 

          Enocder ACT Motor Wiring to MCLV-48V-300W
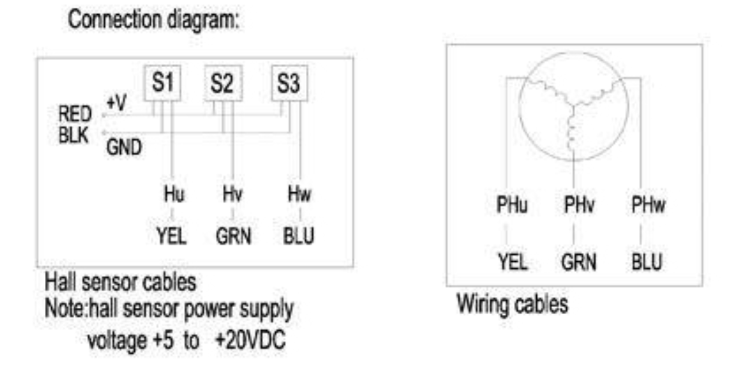
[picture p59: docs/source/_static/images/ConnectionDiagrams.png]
Connection Diagrams
     - 

          Connection Diagrams

**2.2.2 Configure MCLV-48V-300W (DUT)**

For the MCLV-48V-300W you should follow the conenction shown below.

Note that this board hosts the DIM for motor-control algorithms. The motor-side HEX downloads are listed below.

.. tip::

   The `MCLV48_300_DIMhold.stl <https://github.com/ImpressiveTaste/Dyno-MCHP-Repository-WIP/blob/main/3Dparts/STL/MCLV48_300_DIMhold.stl>`_ is not necessary,
   but to guarantee better connection of the **DIM** boards to the MCLV-48V-300W board the suggestion is to 3D print one and use it.

MCLV-48V-300W board configuration

   MCLV-48V-300W board configuration

The DUT board shares the DC-link with the dyno board. Follow the warning and wiring notes on
:doc:`Make Your MC-Dyno <make_your_MC_Dyno>`.

3. Monitor motor behavior with pyX2Cscope
-----------------------------------------

To view motor behavior on the DUT side, you can use `pyX2Cscope <https://x2cscope.github.io/pyx2cscope/>`_ through Python.
There are also standalone apps you can download and run directly without installing anything beyond the app itself.
To download the Standalone App this is the up-to-date link: `pyX2Cscope releases <https://github.com/X2Cscope/pyx2cscope/releases>`_.

.. tip::

   To actually being able to monitor the board, you will need to load to pyX2Cscope the *.elf* file related to the project that is loaded to the board.
   You can find the *.elf* files in the *production* *dist* folder for the project currently loaded on the board.
   All motor control examples by Microchip are already compatible with X2Cscope, so the only thing you need to do is program the board, and load the *.elf* file.
   
   Here is a good video showing how to use *X2Cscope* with some code: `Video Tutorial Example using motorBench® Development Suite <https://youtu.be/Znv0quaTxXc?si=lDy2cfnZS-tfgaD6>`_.

.. list-table::
   :widths: 50 50
   :align: center

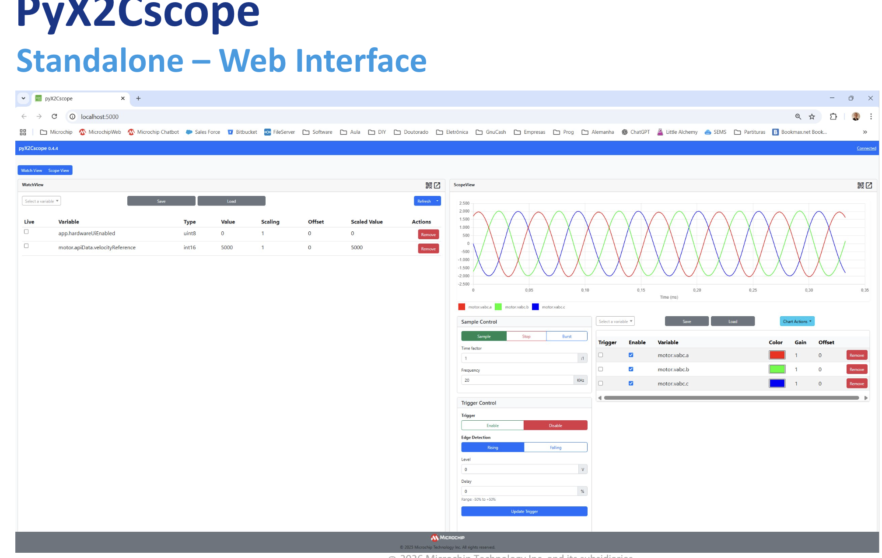
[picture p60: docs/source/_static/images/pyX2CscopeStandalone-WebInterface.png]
pyX2Cscope Standalone Web Interface
   * - 

          pyX2Cscope Standalone Web Interface
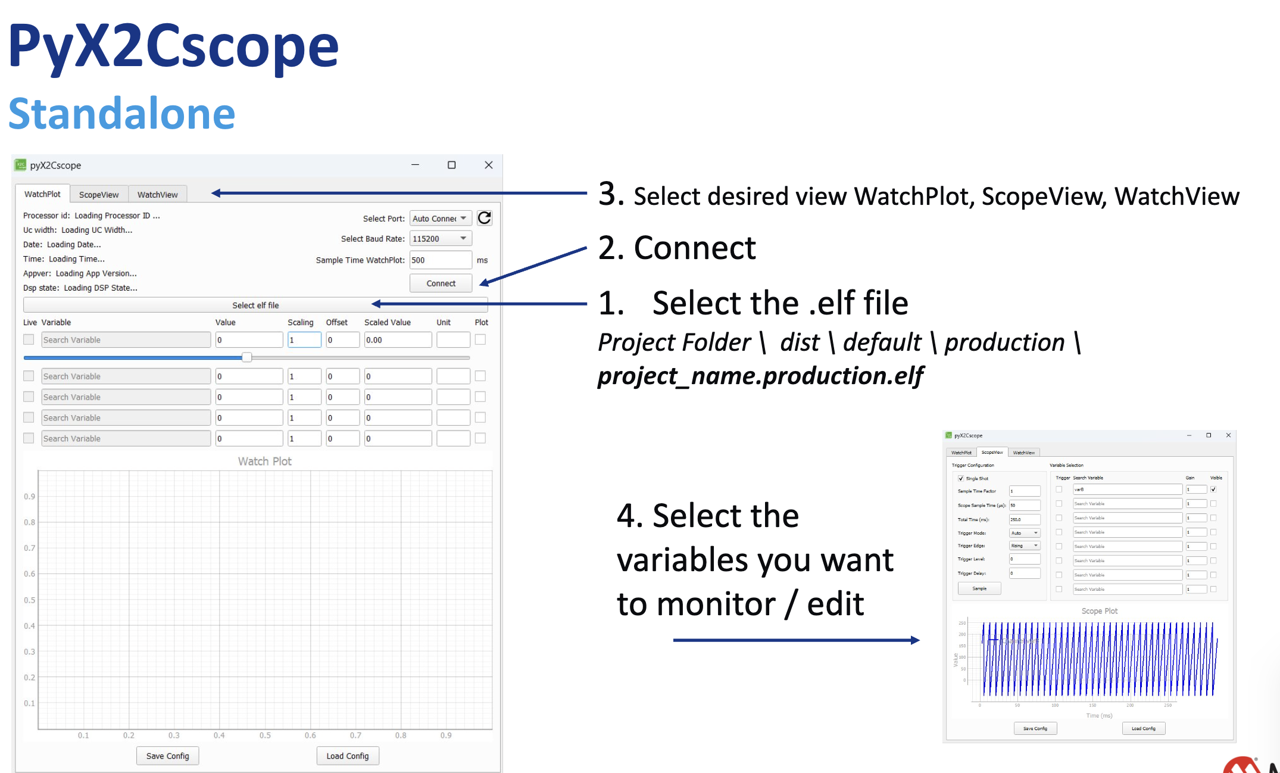
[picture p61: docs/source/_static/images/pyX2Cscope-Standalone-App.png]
pyX2Cscope Standalone App
     - 

          pyX2Cscope Standalone App
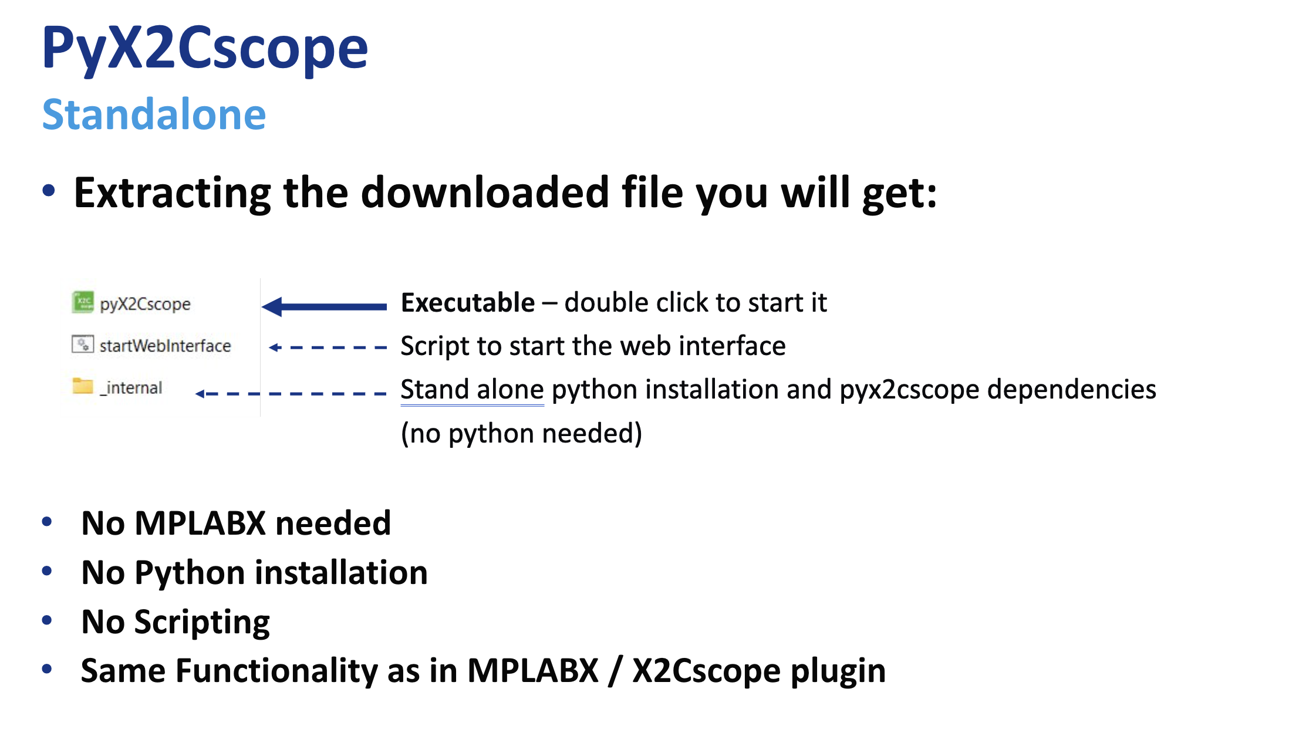
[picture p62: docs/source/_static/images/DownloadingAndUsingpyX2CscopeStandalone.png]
Downloading and using pyX2Cscope Standalone
   * - 

          Downloading and using pyX2Cscope Standalone
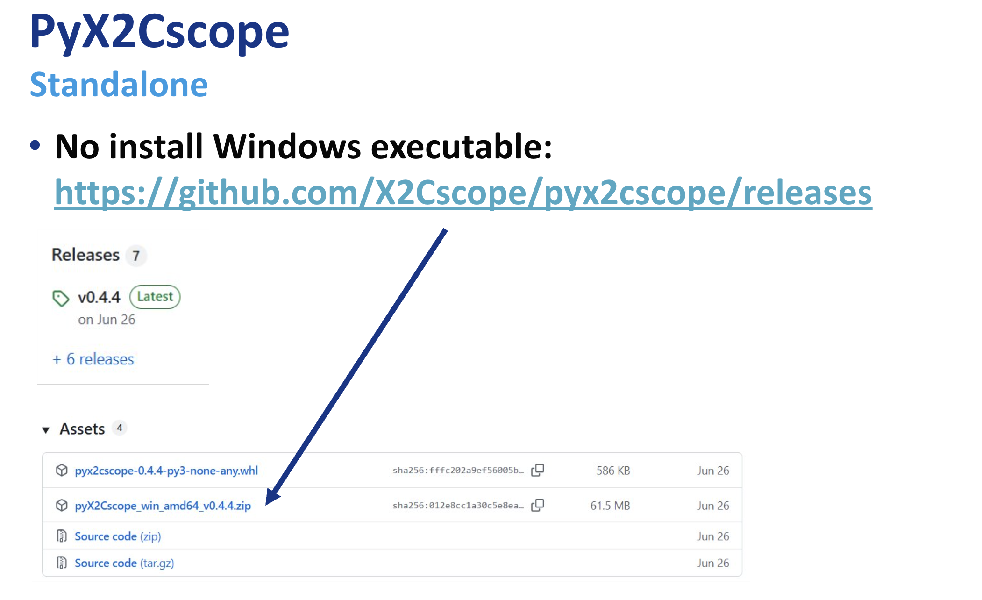
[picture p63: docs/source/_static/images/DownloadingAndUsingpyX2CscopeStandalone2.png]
Downloading and using pyX2Cscope Standalone (2)
     - 

          Downloading and using pyX2Cscope Standalone (2)

These HEX files target the motor-side control DIM installed on the
MCLV-48V-300W Development Board (EV18H47A). They are used to showcase different
motor-control algorithms on the dyno.

Example DIM: dsPIC33CK256MP508 Motor Control DIM (EV62P66A)
https://www.microchip.com/en-us/development-tool/ev62p66a

HEX Location
------------

``motor_ACT57BLF02/mclv48v300w_dim_hex/doc/standalone/``

Downloads
---------

.. container:: motor-dim-downloads

   :download:`Single-shunt (dsPIC33AK128MC106 DIM) <_downloads/dsPIC33AK128MC106_MC_Dyno_08_01_2026_SingleShunt_DIM.hex>`

   :download:`ZS/MT (dsPIC33CK256MP508 DIM) <_downloads/dsPIC33CK256MP508_MC_Dyno_08_01_2026_ZSMT_DIM.hex>`

   :download:`X2C (dsPIC33CK256MP508 DIM) <_downloads/dsPIC33CK256MP508_MC_Dyno_08_01_2026_X2C_DIM.hex>`

   :download:`QuickSpin (ATSAME54P20A DIM) <_downloads/ATSAME54P20A_MC_Dyno_08_01_2026_QuickSpin_DIM.hex>`

   :download:`StreamAnalyze (ATSAME54P20A DIM) <_downloads/ATSAME54P20A_MC_Dyno_08_01_2026_StreamAnalyze_DIM.hex>`

Algorithm Notes
---------------

DIM mapping:

- Single-shunt demo runs on the dsPIC33AK128MC106 DIM.
- ZS/MT and X2C demos run on the dsPIC33CK256MP508 DIM.

Single-shunt current measurement (MCAF R8):

- Samples the DC-link current twice in a single PWM period and reconstructs
  phase currents based on the inverter switching state.
- Requires a dedicated, high-priority ADC ISR and a minimum switching-state
  window (t_sample + dead time).
- For estimators other than ZS/MT, use single update in Dual Edge Center
  Aligned PWM mode.

Zero-Speed / Maximum Torque (ZS/MT) Estimator

ZS/MT is a sensorless position and speed estimation algorithm specifically
designed to operate where back-EMF based estimators fail, at zero and ultra-low
speeds.

Operating Principle - High-Frequency Signal Injection

Unlike PLL-type estimators, ZS/MT is intrusive: it injects a high-frequency
excitation voltage into the stator and measures the motor's response. This
leverages motor saliency to determine rotor angle even at standstill.

Motor Requirements (Saliency)

ZS/MT requires a motor with significant Ld != Lq saliency. It is thus primarily
intended for IPMSM machines, where q-axis inductance is notably higher than
d-axis inductance.

Startup Sequence - IPC for Zero-Speed Torque Production

To deliver torque from standstill, ZS/MT uses a startup procedure termed
"ZS/MT + Initial Position Correction (IPC)", allowing the controller to
correctly align the stator field before any mechanical motion begins.

Hybrid Operation - Low-Speed to High-Speed Transition

Because the injected signal consumes voltage headroom, ZS/MT cannot achieve the
absolute maximum speed by itself. In practice, it is combined with a back-EMF
estimator (for example, PLL) using a hybrid scheme (for example, "Minotaur
hard-switch") to allow:

- ZS/MT for 0-to-low-speed operation
- PLL for mid-to-high-speed operation

Tuning and Configuration Parameters

Reference hardware:
https://www.microchip.com/en-us/development-tool/ev18h47a

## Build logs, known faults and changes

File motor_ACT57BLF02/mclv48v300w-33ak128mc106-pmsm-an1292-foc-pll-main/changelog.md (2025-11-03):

# mclv48v300w-33ak128mc106-pmsm-an1292-foc-pll v2.0.0
### Release Highlights
This is the second version of code for sensorless field oriented control of PMSM using PLL estimator on MCLV-48V-300W board(EV18H47A) with dsPIC33AK128MC106 MC DIM(EV68M17A). 

The code is set up for running the following motos,
- Hurst300 Motor(DMA0204024B101 - [AC300022](https://www.microchip.com/en-us/development-tool/AC300022)) (by default)
- Hurst075 Motor(DMB0224C10002 - [AC300020](https://www.microchip.com/en-us/development-tool/AC300020))
- Leadshine Servo Motor [(ELVM6020V24FH-B25-HD)](https://www.leadshine.com/product-detail/ELVM6020V24FH-B25-HD.html)

All the motors are tested under no load conditions. To achieve optimal performance under loaded conditions, the control parameters in the firmware may need additional tuning.

### Features Added\Updated
- Code flow is managed by State Machines to allow seamless integration of load-specific algorithms and application-specific communication interfaces
- Supports Dual Shunt(phase shunts) and Single Shunt(bus shunt) current measurement schemes
- Integrates two variants of flux weakening,
    1. PI controller based on voltage circle limit (less dependent on motor parameters)
    2. Reference speed feed-forward control based on PMSM steady state equations(Id reference is computed from motor parameters); can be used when motor parameters are accurately known
- Supports an additional motor; 24V Leadshine Servo Motor [(ELVM6020V24FH-B25-HD)](https://www.leadshine.com/product-detail/ELVM6020V24FH-B25-HD.html)
- DC bus voltage compensation
- Assigned functions of push buttons and potentiometer in the firmware:
	1. Push Button #1(SW1) starts and stops motor. The Speed of the motor can be controlled using potentiometer in its entire speed range. Please note that the motor operates in the flux-weakening region beyond its nominal speed.
	2. Push Button #2(SW2) changes the direction of rotation
- Supports forward and reverse rotation of motor
- Improved start-up and closed loop transition
- Over Current Fault
	1. Software limit on the phase current
	2. DC Bus current protection using dsPIC features such as PWM PCI, comparator and DAC

# mclv48v300w-33ak128mc106-pmsm-an1292-foc-pll v1.0.0
### Release Highlights
This is the first version of code for sensorless field oriented control of PMSM using PLL estimator on MCLV-48V-300W board(EV18H47A) with dsPIC33AK128MC106 MC DIM(EV68M17A). 
The code is set up for running Hurst300 Motor(DMA0204024B101 - AC300022) (by default), Hurst075 Motor(DMB0224C10002 - AC300020)
All the motors are tested under no load conditions. To achieve optimal performance under loaded conditions, the control parameters in the firmware may need additional tuning.

### Features Added\Updated

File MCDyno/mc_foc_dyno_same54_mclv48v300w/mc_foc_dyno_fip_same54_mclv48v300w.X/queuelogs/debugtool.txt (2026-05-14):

1017 1778759320804 GEN4_CONNECT_DIAGNOSTICS:MPLABCommTool is NOT null
1017 1778759320805 GEN4_CONNECT_DIAGNOSTICS:AttachedToolPID = 810b, AttachedToolVID = 4d8
1017 1778759320805 GEN4_CONNECT_DIAGNOSTICS:transport type = USB
1017 1778759320806 GEN4_CONNECT_DIAGNOSTICS:AttachedToolPID = 810b, AttachedToolVID = 4d8
1017 1778759320887 com.microchip.mplab.mdbcore.RealICETool.RIDbgToolCom
1017 1778759320887 GEN4_CONNECT_DIAGNOSTICS:Before MPLABCommTool.Connect()
1017 1778759320887 GEN4_CONNECT_DIAGNOSTICS:After MPLABCommTool.Connect()
1017 1778759320913 GEN4_CONNECT_DIAGNOSTICS:Adding new plug and play observer com.microchip.mplab.mdbcore.RI4Tool.RI4ToolBase$RI4PlugNPlayObserver@15a889b9
1017 1778759320913 GEN4_CONNECT_DIAGNOSTICS:Begin PlugNPlayObservers list dump:
1017 1778759320913 GEN4_CONNECT_DIAGNOSTICS:com.microchip.mplab.mdbcore.RI4Tool.RI4ToolBase$RI4PlugNPlayObserver@15a889b9
1017 1778759320913 GEN4_CONNECT_DIAGNOSTICS:End PlugNPlayObservers list dump:
1017 1778759320918 GEN4_CONNECT_DIAGNOSTICS:Registering for alternate PNP notifications. CommPnPCriteria.cPIDList = [810A, 8109, 2184], CommPnPCriteria.cSerialNumber = 020012202ryn000072

1017 1778759322144 GEN4_TO_CONTROLLER_LOG:GEN4_INIT_INT_LOG_ATSAME54P20A Pre:init
1017 1778759322144 GEN4_TO_CONTROLLER_LOG:GEN4_INIT_INT_LOG_ATSAME54P20A Payload
1017 1778759322145 GEN4_TO_CONTROLLER_LOG:GEN4_INIT_INT_LOG_ATSAME54P20A DeviceInfo: Values:
1017 1778759322145 GEN4_TO_CONTROLLER_LOG:GEN4_INIT_INT_LOG_ATSAME54P20A DeviceInfo: pcAddress = 7fffffffffffffff, Vpp = 3,30, useRowEraseIfVoltageIsLow = false, voltageBelowWhichUseRowErase = 0,00, deviceName = ATSAME54P20A, programmerType = NVMCTRL_U2409
1017 1778759322145 GEN4_TO_CONTROLLER_LOG:GEN4_INIT_INT_LOG_ATSAME54P20A DeviceInfo: MemInfo values:
1017 1778759322145 GEN4_TO_CONTROLLER_LOG:GEN4_INIT_INT_LOG_ATSAME54P20A DeviceInfo: mask = ffffffff, exists = true, startAddr = 00000000, endAddr = 47001fff, rowSize = 2000, rowEraseSize = 2000, addrInc = 0004, widthProgram = 0004
1017 1778759322146 GEN4_TO_CONTROLLER_LOG:GEN4_INIT_INT_LOG_ATSAME54P20A DeviceInfo: mask = ffffffff, exists = true, startAddr = 00804000, endAddr = 0080400b, rowSize = 0001, rowEraseSize = 0000, addrInc = 0004, widthProgram = 0004
1017 1778759322146 GEN4_TO_CONTROLLER_LOG:GEN4_INIT_INT_LOG_ATSAME54P20A DeviceInfo: mask = 0000, exists = false, startAddr = 00000000, endAddr = 00000000, rowSize = 0000, rowEraseSize = 2000, addrInc = 0000, widthProgram = 0000
1017 1778759322146 GEN4_TO_CONTROLLER_LOG:GEN4_INIT_INT_LOG_ATSAME54P20A DeviceInfo: mask = 0000, exists = false, startAddr = 00000000, endAddr = 00000000, rowSize = 0000, rowEraseSize = 0000, addrInc = 0000, widthProgram = 0000
1017 1778759322146 GEN4_TO_CONTROLLER_LOG:GEN4_INIT_INT_LOG_ATSAME54P20A DeviceInfo: mask = ffffffff, exists = true, startAddr = 0080400c, endAddr = 008041ff, rowSize = 0200, rowEraseSize = 0000, addrInc = 0004, widthProgram = 0004
1017 1778759322146 GEN4_TO_CONTROLLER_LOG:GEN4_INIT_INT_LOG_ATSAME54P20A DeviceInfo: mask = 0000, exists = false, startAddr = 00000000, endAddr = 00000000, rowSize = 0000, rowEraseSize = 2000, addrInc = 0000, widthProgram = 0000
1017 1778759322146 GEN4_TO_CONTROLLER_LOG:GEN4_INIT_INT_LOG_ATSAME54P20A DeviceInfo: mask = 0000, exists = false, startAddr = 00000000, endAddr = 00000000, rowSize = 0000, rowEraseSize = 0000, addrInc = 0004, widthProgram = 0004
1017 1778759322146 GEN4_TO_CONTROLLER_LOG:GEN4_INIT_INT_LOG_ATSAME54P20A DeviceInfo: mask = ffffffff, exists = true, startAddr = 03000000, endAddr = e0041fff, rowSize = 0000, rowEraseSize = 0000, addrInc = 0004, widthProgram = 0004
1017 1778759322146 GEN4_TO_CONTROLLER_LOG:GEN4_INIT_INT_LOG_ATSAME54P20A DeviceInfo: mask = 0000, exists = false, startAddr = 00000000, endAddr = 00000000, rowSize = 0000, rowEraseSize = 0000, addrInc = 0000, widthProgram = 0000
1017 1778759322146 GEN4_TO_CONTROLLER_LOG:GEN4_INIT_INT_LOG_ATSAME54P20A DeviceInfo: mask = 0000, exists = false, startAddr = 00000000, endAddr = 00000000, rowSize = 0000, rowEraseSize = 0000, addrInc = 0000, widthProgram = 0000
1017 1778759322146 GEN4_TO_CONTROLLER_LOG:GEN4_INIT_INT_LOG_ATSAME54P20A DeviceInfo: mask = 0000, exists = false, startAddr = 00000000, endAddr = 00000000, rowSize = 0000, rowEraseSize = 0000, addrInc = 0004, widthProgram = 0004
1017 1778759322146 GEN4_TO_CONTROLLER_LOG:GEN4_INIT_INT_LOG_ATSAME54P20A DeviceInfo: mask = 0000, exists = false, startAddr = 00000000, endAddr = 00000000, rowSize = 0000, rowEraseSize = 0000, addrInc = 0004, widthProgram = 0004
1017 1778759322146 GEN4_TO_CONTROLLER_LOG:GEN4_INIT_INT_LOG_ATSAME54P20A DeviceInfo: mask = 0000, exists = false, startAddr = 00000000, endAddr = 00000000, rowSize = 0000, rowEraseSize = 0000, addrInc = 0000, widthProgram = 0000
1017 1778759322146 GEN4_TO_CONTROLLER_LOG:GEN4_INIT_INT_LOG_ATSAME54P20A DeviceInfo: mask = 0000, exists = false, startAddr = 00000000, endAddr = 00000000, rowSize = 0000, rowEraseSize = 0000, addrInc = 0000, widthProgram = 0000
1017 1778759322146 GEN4_TO_CONTROLLER_LOG:GEN4_INIT_INT_LOG_ATSAME54P20A DeviceInfo: mask = 0000, exists = false, startAddr = 00000000, endAddr = 00000000, rowSize = 0000, rowEraseSize = 0000, addrInc = 0000, widthProgram = 0000
1017 1778759322146 GEN4_TO_CONTROLLER_LOG:GEN4_INIT_INT_LOG_ATSAME54P20A DeviceInfo: mask = 0000, exists = false, startAddr = 00000000, endAddr = 00000000, rowSize = 0000, rowEraseSize = 0000, addrInc = 0000, widthProgram = 0000
1017 1778759322146 GEN4_TO_CONTROLLER_LOG:GEN4_INIT_INT_LOG_ATSAME54P20A DeviceInfo: mask = 7fffffff, exists = true, startAddr = 41002018, endAddr = 4100201b, rowSize = 0001, rowEraseSize = 0000, addrInc = 0001, widthProgram = 0001
1017 1778759322146 GEN4_TO_CONTROLLER_LOG:GEN4_INIT_INT_LOG_ATSAME54P20A DeviceInfo: mask = 0000, exists = false, startAddr = 00000000, endAddr = 00000000, rowSize = 0000, rowEraseSize = 0000, addrInc = 0000, widthProgram = 0000
1017 1778759322146 GEN4_TO_CONTROLLER_LOG:GEN4_INIT_INT_LOG_ATSAME54P20A DeviceInfo: mask = 0000, exists = false, startAddr = 00000000, endAddr = 00000000, rowSize = 0000, rowEraseSize = 0000, addrInc = 0000, widthProgram = 0000
1017 1778759322146 GEN4_TO_CONTROLLER_LOG:GEN4_INIT_INT_LOG_ATSAME54P20A DeviceInfo: mask = 0000, exists = false, startAddr = 00000000, endAddr = 00000000, rowSize = 0000, rowEraseSize = 0000, addrInc = 0000, widthProgram = 0000
1017 1778759322146 GEN4_TO_CONTROLLER_LOG:GEN4_INIT_INT_LOG_ATSAME54P20A DeviceInfo: mask = 0000, exists = false, startAddr = 00000000, endAddr = 00000000, rowSize = 0000, rowEraseSize = 0000, addrInc = 0000, widthProgram = 0000
1017 1778759322146 GEN4_TO_CONTROLLER_LOG:GEN4_INIT_INT_LOG_ATSAME54P20A DeviceInfo: mask = 0000, exists = false, startAddr = 00000000, endAddr = 00000000, rowSize = 0000, rowEraseSize = 0000, addrInc = 0000, widthProgram = 0000
1017 1778759322146 GEN4_TO_CONTROLLER_LOG:GEN4_INIT_INT_LOG_ATSAME54P20A DeviceInfo: mask = 0000, exists = false, startAddr = 00000000, endAddr = 00000000, rowSize = 0000, rowEraseSize = 0000, addrInc = 0000, widthProgram = 0000
1017 1778759322146 GEN4_TO_CONTROLLER_LOG:GEN4_INIT_INT_LOG_ATSAME54P20A CfgRequiredBitsMask Values:
1017 1778759322146 GEN4_TO_CONTROLLER_LOG:GEN4_INIT_INT_LOG_ATSAME54P20A Address = 00804000, Mask = 3c007fff
1017 1778759322146 GEN4_TO_CONTROLLER_LOG:GEN4_INIT_INT_LOG_ATSAME54P20A Address = 00804004, Mask = 7fff00ff
1017 1778759322146 GEN4_TO_CONTROLLER_LOG:GEN4_INIT_INT_LOG_ATSAME54P20A Address = 00804008, Mask = ffffffff
1017 1778759322146 GEN4_TO_CONTROLLER_LOG:GEN4_INIT_INT_LOG_ATSAME54P20A BasicInfo: Values:
1017 1778759322147 GEN4_TO_CONTROLLER_LOG:GEN4_INIT_INT_LOG_ATSAME54P20A BasicInfo: InputStream = com.microchip.mplab.libs.toolpacksupport.EquatableFileInputStream@84f7700a, ToolFlavor = PICKit4
1017 1778759322147 GEN4_TO_CONTROLLER_LOG:GEN4_INIT_INT_LOG_ATSAME54P20A Payload End
1017 1778759332128 GEN4_TO_CONTROLLER_LOG:GEN4_INIT_INT_LOG_ATSAME54P20A Post:init
1017 1778759332128 GEN4_TO_CONTROLLER_LOG:GEN4_INIT_INT_LOG_ATSAME54P20A Return Value
1017 1778759332128 GEN4_TO_CONTROLLER_LOG:GEN4_INIT_INT_LOG_ATSAME54P20A none
1017 1778759332128 GEN4_TO_CONTROLLER_LOG:GEN4_INIT_INT_LOG_ATSAME54P20A Return End

1017 1778759332128 GEN4_TO_CONTROLLER_LOG:GEN4_INIT_INT_LOG_ATSAME54P20A Pre:GetInterfaceProvider
1017 1778759332128 GEN4_TO_CONTROLLER_LOG:GEN4_INIT_INT_LOG_ATSAME54P20A Payload
1017 1778759332128 GEN4_TO_CONTROLLER_LOG:GEN4_INIT_INT_LOG_ATSAME54P20A RI4DebugInterface
1017 1778759332128 GEN4_TO_CONTROLLER_LOG:GEN4_INIT_INT_LOG_ATSAME54P20A Payload End
1017 1778759332129 GEN4_TO_CONTROLLER_LOG:GEN4_INIT_INT_LOG_ATSAME54P20A Post:GetInterfaceProvider
1017 1778759332129 GEN4_TO_CONTROLLER_LOG:GEN4_INIT_INT_LOG_ATSAME54P20A Return Value
1017 1778759332129 GEN4_TO_CONTROLLER_LOG:GEN4_INIT_INT_LOG_ATSAME54P20A com.microchip.mplab.libs.RI4ToolsController.implementations.RI4DebugInterfaceImpl@a0ac653
1017 1778759332129 GEN4_TO_CONTROLLER_LOG:GEN4_INIT_INT_LOG_ATSAME54P20A Return End

1017 1778759332184 GEN4_TO_CONTROLLER_LOG:GEN4_INIT_INT_LOG_ATSAME54P20A Pre:GetInterfaceProvider
1017 1778759332184 GEN4_TO_CONTROLLER_LOG:GEN4_INIT_INT_LOG_ATSAME54P20A Payload
1017 1778759332184 GEN4_TO_CONTROLLER_LOG:GEN4_INIT_INT_LOG_ATSAME54P20A RI4ProgramInterface
1017 1778759332184 GEN4_TO_CONTROLLER_LOG:GEN4_INIT_INT_LOG_ATSAME54P20A Payload End
1017 1778759332184 GEN4_TO_CONTROLLER_LOG:GEN4_INIT_INT_LOG_ATSAME54P20A Post:GetInterfaceProvider
1017 1778759332184 GEN4_TO_CONTROLLER_LOG:GEN4_INIT_INT_LOG_ATSAME54P20A Return Value
1017 1778759332184 GEN4_TO_CONTROLLER_LOG:GEN4_INIT_INT_LOG_ATSAME54P20A com.microchip.mplab.libs.RI4ToolsController.implementations.RI4ProgramInterfaceImpl@2d24c9c5
1017 1778759332184 GEN4_TO_CONTROLLER_LOG:GEN4_INIT_INT_LOG_ATSAME54P20A Return End

1017 1778759332234 GEN4_TO_CONTROLLER_LOG:GEN4_INIT_INT_LOG_ATSAME54P20A Pre:GetInterfaceProvider
1017 1778759332234 GEN4_TO_CONTROLLER_LOG:GEN4_INIT_INT_LOG_ATSAME54P20A Payload
1017 1778759332234 GEN4_TO_CONTROLLER_LOG:GEN4_INIT_INT_LOG_ATSAME54P20A RI4ConnectInterface
1017 1778759332234 GEN4_TO_CONTROLLER_LOG:GEN4_INIT_INT_LOG_ATSAME54P20A Payload End
1017 1778759332237 GEN4_TO_CONTROLLER_LOG:GEN4_INIT_INT_LOG_ATSAME54P20A Post:GetInterfaceProvider
1017 1778759332237 GEN4_TO_CONTROLLER_LOG:GEN4_INIT_INT_LOG_ATSAME54P20A Return Value
1017 1778759332237 GEN4_TO_CONTROLLER_LOG:GEN4_INIT_INT_LOG_ATSAME54P20A com.microchip.mplab.libs.PK4ToolsController.PK4ConnectInterfaceImpl@1d6821e8
1017 1778759332237 GEN4_TO_CONTROLLER_LOG:GEN4_INIT_INT_LOG_ATSAME54P20A Return End
1017 1778759332254 GEN4_CONNECT_DIAGNOSTICS:acceptablePIDs = [810a, 8109, 810b]
1017 1778759332254 GEN4_CONNECT_DIAGNOSTICS:otherPIDs = [2184]
1017 1778759332254 GEN4_CONNECT_DIAGNOSTICS:Setting selected tool type to pk4
1017 1778759332255 GEN4_CONNECT_DIAGNOSTICS:otherPIDs = [2184]
1017 1778759332255 GEN4_CONNECT_DIAGNOSTICS:acceptablePIDs = [810a, 8109, 810b]

1017 1778759332260 GEN4_TO_CONTROLLER_LOG:GEN4_CONNECT_INT_LOG_ATSAME54P20A Pre:selectCore
1017 1778759332260 GEN4_TO_CONTROLLER_LOG:GEN4_CONNECT_INT_LOG_ATSAME54P20A Payload
1017 1778759332260 GEN4_TO_CONTROLLER_LOG:GEN4_CONNECT_INT_LOG_ATSAME54P20A ATSAME54P20A
1017 1778759332260 GEN4_TO_CONTROLLER_LOG:GEN4_CONNECT_INT_LOG_ATSAME54P20A Payload End
1017 1778759332260 GEN4_TO_CONTROLLER_LOG:GEN4_CONNECT_INT_LOG_ATSAME54P20A Post:selectCore
1017 1778759332260 GEN4_TO_CONTROLLER_LOG:GEN4_CONNECT_INT_LOG_ATSAME54P20A Return Value
1017 1778759332260 GEN4_TO_CONTROLLER_LOG:GEN4_CONNECT_INT_LOG_ATSAME54P20A none
1017 1778759332260 GEN4_TO_CONTROLLER_LOG:GEN4_CONNECT_INT_LOG_ATSAME54P20A Return End

1017 1778759332260 GEN4_TO_CONTROLLER_LOG:GEN4_INIT_INT_LOG_ATSAME54P20A Pre:GetInterfaceProvider
1017 1778759332260 GEN4_TO_CONTROLLER_LOG:GEN4_INIT_INT_LOG_ATSAME54P20A Payload
1017 1778759332260 GEN4_TO_CONTROLLER_LOG:GEN4_INIT_INT_LOG_ATSAME54P20A RI4ControllerDiagnosticsInterface
1017 1778759332260 GEN4_TO_CONTROLLER_LOG:GEN4_INIT_INT_LOG_ATSAME54P20A Payload End
1017 1778759332260 GEN4_TO_CONTROLLER_LOG:GEN4_INIT_INT_LOG_ATSAME54P20A Post:GetInterfaceProvider
1017 1778759332260 GEN4_TO_CONTROLLER_LOG:GEN4_INIT_INT_LOG_ATSAME54P20A Return Value
1017 1778759332260 GEN4_TO_CONTROLLER_LOG:GEN4_INIT_INT_LOG_ATSAME54P20A com.microchip.mplab.libs.RI4ToolsController.implementations.RI4ControllerDiagnosticsInterfaceImpl@4575138f
1017 1778759332260 GEN4_TO_CONTROLLER_LOG:GEN4_INIT_INT_LOG_ATSAME54P20A Return End

1017 1778759332260 GEN4_TO_CONTROLLER_LOG:GEN4_INIT_INT_LOG_ATSAME54P20A Pre:GetInterfaceProvider
1017 1778759332260 GEN4_TO_CONTROLLER_LOG:GEN4_INIT_INT_LOG_ATSAME54P20A Payload
1017 1778759332260 GEN4_TO_CONTROLLER_LOG:GEN4_INIT_INT_LOG_ATSAME54P20A ProgrammerToGo
1017 1778759332260 GEN4_TO_CONTROLLER_LOG:GEN4_INIT_INT_LOG_ATSAME54P20A Payload End
1017 1778759332260 GEN4_TO_CONTROLLER_LOG:GEN4_INIT_INT_LOG_ATSAME54P20A Post:GetInterfaceProvider
1017 1778759332260 GEN4_TO_CONTROLLER_LOG:GEN4_INIT_INT_LOG_ATSAME54P20A Return Value
1017 1778759332260 GEN4_TO_CONTROLLER_LOG:GEN4_INIT_INT_LOG_ATSAME54P20A com.microchip.mplab.libs.RI4ToolsController.implementations.ProgrammerToGoImpl@5f94826a
1017 1778759332260 GEN4_TO_CONTROLLER_LOG:GEN4_INIT_INT_LOG_ATSAME54P20A Return End

1017 1778759332263 GEN4_TO_CONTROLLER_LOG:GEN4_INIT_INT_LOG_ATSAME54P20A Pre:GetInterfaceProvider
1017 1778759332263 GEN4_TO_CONTROLLER_LOG:GEN4_INIT_INT_LOG_ATSAME54P20A Payload
1017 1778759332263 GEN4_TO_CONTROLLER_LOG:GEN4_INIT_INT_LOG_ATSAME54P20A Status
1017 1778759332263 GEN4_TO_CONTROLLER_LOG:GEN4_INIT_INT_LOG_ATSAME54P20A Payload End
1017 1778759332263 GEN4_TO_CONTROLLER_LOG:GEN4_INIT_INT_LOG_ATSAME54P20A Post:GetInterfaceProvider
1017 1778759332263 GEN4_TO_CONTROLLER_LOG:GEN4_INIT_INT_LOG_ATSAME54P20A Return Value
1017 1778759332263 GEN4_TO_CONTROLLER_LOG:GEN4_INIT_INT_LOG_ATSAME54P20A null
1017 1778759332263 GEN4_TO_CONTROLLER_LOG:GEN4_INIT_INT_LOG_ATSAME54P20A Return End
1017 1778759332276 GEN4_CONNECT_DIAGNOSTICS:ENTERING: com.microchip.mplab.mdbcore.RI4Tool.ConnectionHandler.CheckForFWUpdates()
1017 1778759332276 GEN4_CONNECT_DIAGNOSTICS:Created FirmwareUpdateHandler com.microchip.mplab.mdbcore.pk4hybrid.pk4hybridFirmwareUpdateHandler@243a4a6b
1017 1778759332276 GEN4_CONNECT_DIAGNOSTICS:ENTERING: com.microchip.mplab.mdbcore.pk4hybrid.pk4hybridFirmwareUpdateHandler.UpdateFirmware(FirmwareInfo, UpdateMessage)
1017 1778759332284 GEN4_CONNECT_DIAGNOSTICS:areWeInBoot returned false
1017 1778759332284 GEN4_CONNECT_DIAGNOSTICS:inBoot = false
1017 1778759332284 GEN4_CONNECT_DIAGNOSTICS:uMode = checkingVersions
1017 1778759332284 GEN4_CONNECT_DIAGNOSTICS:selectedTool = pk4
1017 1778759332284 GEN4_CONNECT_DIAGNOSTICS:current toolType = pk4
1017 1778759332284 GEN4_CONNECT_DIAGNOSTICS:current tool mode = pk4
1017 1778759332284 GEN4_CONNECT_DIAGNOSTICS:ENTERING: com.microchip.mplab.mdbcore.pk4hybrid.pk4hybridFirmwareUpdateHandler.GetUpdateInfo()
1017 1778759332288 GEN4_CONNECT_DIAGNOSTICS:Parsing file  for firmware updates
1017 1778759332288 GEN4_CONNECT_DIAGNOSTICS:ENTERING: com.microchip.mplab.mdbcore.pk4hybrid.pk4hybridFirmwareUpdateHandler.ParseSelectedVersionsFromJamFile()
1017 1778759332288 GEN4_CONNECT_DIAGNOSTICS:Jame file line = pkob4_boot.hex,010141
1017 1778759332288 GEN4_CONNECT_DIAGNOSTICS:Jame file line = scripts.xml,001008
1017 1778759332288 GEN4_CONNECT_DIAGNOSTICS:Jame file line = pkob4_app1 001002, 0040C000
1017 1778759332289 GEN4_CONNECT_DIAGNOSTICS:EXITING: com.microchip.mplab.mdbcore.pk4hybrid.pk4hybridFirmwareUpdateHandler.ri4ParseSelectedVersionsFromJamFile()
1017 1778759332289 GEN4_CONNECT_DIAGNOSTICS:EXITING: com.microchip.mplab.mdbcore.pk4hybrid.pk4hybridFirmwareUpdateHandler.GetUpdateInfo()
1017 1778759332289 GEN4_CONNECT_DIAGNOSTICS:current toolType = pk4

1017 1778759332289 GEN4_TO_CONTROLLER_LOG:GEN4_CONNECT_INT_LOG_ATSAME54P20A Pre:EstablishCommunincations
1017 1778759332289 GEN4_TO_CONTROLLER_LOG:GEN4_CONNECT_INT_LOG_ATSAME54P20A Payload
1017 1778759332289 GEN4_TO_CONTROLLER_LOG:GEN4_CONNECT_INT_LOG_ATSAME54P20A com.microchip.mplab.mdbcore.PK4Tool.PK4Com@21c888e3
1017 1778759332289 GEN4_TO_CONTROLLER_LOG:GEN4_CONNECT_INT_LOG_ATSAME54P20A Payload End
1017 1778759332304 GEN4_TO_CONTROLLER_LOG:GEN4_CONNECT_INT_LOG_ATSAME54P20A Post:EstablishCommunincations
1017 1778759332304 GEN4_TO_CONTROLLER_LOG:GEN4_CONNECT_INT_LOG_ATSAME54P20A Return Value
1017 1778759332306 GEN4_TO_CONTROLLER_LOG:GEN4_CONNECT_INT_LOG_ATSAME54P20A true
1017 1778759332306 GEN4_TO_CONTROLLER_LOG:GEN4_CONNECT_INT_LOG_ATSAME54P20A Return End

1017 1778759332306 GEN4_TO_CONTROLLER_LOG:GEN4_CONNECT_INT_LOG_ATSAME54P20A Pre:GetFirmwareInfo
1017 1778759332306 GEN4_TO_CONTROLLER_LOG:GEN4_CONNECT_INT_LOG_ATSAME54P20A Payload
1017 1778759332306 GEN4_TO_CONTROLLER_LOG:GEN4_CONNECT_INT_LOG_ATSAME54P20A null
1017 1778759332306 GEN4_TO_CONTROLLER_LOG:GEN4_CONNECT_INT_LOG_ATSAME54P20A Payload End
1017 1778759332313 XXXX 1778759332313, Thread 1017: com.Send returned false 
1017 1778759332315 XXXX 1778759332315, Thread 1017: execCommand: exception after writeSideChanel null

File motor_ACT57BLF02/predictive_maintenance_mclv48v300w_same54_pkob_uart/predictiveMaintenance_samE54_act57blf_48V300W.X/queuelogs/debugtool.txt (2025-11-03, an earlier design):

2275 1737967029117 GEN4_CONNECT_DIAGNOSTICS:MPLABCommTool is null

2275 1737967029117 GEN4_TO_CONTROLLER_LOG:GEN4_CONNECT_INT_LOG_ATSAME54P20A Pre:GetFirmwareInfo
2275 1737967029117 GEN4_TO_CONTROLLER_LOG:GEN4_CONNECT_INT_LOG_ATSAME54P20A Payload
2275 1737967029117 GEN4_TO_CONTROLLER_LOG:GEN4_CONNECT_INT_LOG_ATSAME54P20A null
2275 1737967029117 GEN4_TO_CONTROLLER_LOG:GEN4_CONNECT_INT_LOG_ATSAME54P20A Payload End
2275 1737967032568 XXXX 1737967032568, Thread 2275: ToolCommUsb::read, com.Received returned -1 
2275 1737967032568 XXXX 1737967032568, Thread 2275: execCommand: exception after readSideChannel null 
2275 1737967032568 GEN4_CONNECT_DIAGNOSTICS:Removing plug and play observer com.microchip.mplab.mdbcore.RI4Tool.RI4ToolBase$RI4PlugNPlayObserver@4a1a21a7
2275 1737967032568 GEN4_CONNECT_DIAGNOSTICS:Begin PlugNPlayObservers list dump:
2275 1737967032568 GEN4_CONNECT_DIAGNOSTICS:End PlugNPlayObservers list dump:
2275 1737967032619 GEN4_CONNECT_DIAGNOSTICS:Calling RIDbgToolCom.Disconnect
2275 1737967032619 GEN4_CONNECT_DIAGNOSTICS:Calling MPLABCommTool.Detach to remove tool from plug and play list
2275 1737967032619 GEN4_CONNECT_DIAGNOSTICS:Calling RIDbgToolCom.DisconnectFromMPlabComm
2275 1737967032619 GEN4_CONNECT_DIAGNOSTICS:Calling MPLABCommTool.Disconnect
2286 1737967039719 GEN4_CONNECT_DIAGNOSTICS:MPLABCommTool is NOT null
2286 1737967039719 GEN4_CONNECT_DIAGNOSTICS:AttachedToolPID = 810b, AttachedToolVID = 4d8
2286 1737967039719 GEN4_CONNECT_DIAGNOSTICS:transport type = USB
2286 1737967039719 GEN4_CONNECT_DIAGNOSTICS:AttachedToolPID = 810b, AttachedToolVID = 4d8
2286 1737967039754 com.microchip.mplab.mdbcore.RealICETool.RIDbgToolCom
2286 1737967039754 GEN4_CONNECT_DIAGNOSTICS:Before MPLABCommTool.Connect()
2286 1737967039770 GEN4_CONNECT_DIAGNOSTICS:After MPLABCommTool.Connect()
2286 1737967039770 GEN4_CONNECT_DIAGNOSTICS:MPLABCommTool.Connect() returned MPLABCOMM_NO_ERROR
2286 1737967039771 GEN4_CONNECT_DIAGNOSTICS:Attaching to MPLABCommTool plugnplay
2286 1737967039771 GEN4_CONNECT_DIAGNOSTICS:Adding new plug and play observer com.microchip.mplab.mdbcore.RI4Tool.RI4ToolBase$RI4PlugNPlayObserver@34708d50
2286 1737967039771 GEN4_CONNECT_DIAGNOSTICS:Begin PlugNPlayObservers list dump:
2286 1737967039771 GEN4_CONNECT_DIAGNOSTICS:com.microchip.mplab.mdbcore.RI4Tool.RI4ToolBase$RI4PlugNPlayObserver@34708d50
2286 1737967039771 GEN4_CONNECT_DIAGNOSTICS:End PlugNPlayObservers list dump:
2286 1737967039771 GEN4_CONNECT_DIAGNOSTICS:Registering for alternate PNP notifications. CommPnPCriteria.cPIDList = [810A, 8109, 2184], CommPnPCriteria.cSerialNumber = 020012202ryn000072

2286 1737967039848 GEN4_TO_CONTROLLER_LOG:GEN4_INIT_INT_LOG_ATSAME54P20A Pre:init
2286 1737967039848 GEN4_TO_CONTROLLER_LOG:GEN4_INIT_INT_LOG_ATSAME54P20A Payload
2286 1737967039848 GEN4_TO_CONTROLLER_LOG:GEN4_INIT_INT_LOG_ATSAME54P20A DeviceInfo: Values:
2286 1737967039848 GEN4_TO_CONTROLLER_LOG:GEN4_INIT_INT_LOG_ATSAME54P20A DeviceInfo: pcAddress = 7fffffffffffffff, Vpp = 3.30, useRowEraseIfVoltageIsLow = false, voltageBelowWhichUseRowErase = 0.00, deviceName = ATSAME54P20A, programmerType = NVMCTRL_U2409
2286 1737967039848 GEN4_TO_CONTROLLER_LOG:GEN4_INIT_INT_LOG_ATSAME54P20A DeviceInfo: MemInfo values:
2286 1737967039848 GEN4_TO_CONTROLLER_LOG:GEN4_INIT_INT_LOG_ATSAME54P20A DeviceInfo: mask = ffffffff, exists = true, startAddr = 00000000, endAddr = 47001fff, rowSize = 2000, rowEraseSize = 2000, addrInc = 0004, widthProgram = 0004
2286 1737967039848 GEN4_TO_CONTROLLER_LOG:GEN4_INIT_INT_LOG_ATSAME54P20A DeviceInfo: mask = ffffffff, exists = true, startAddr = 00804000, endAddr = 0080400b, rowSize = 0001, rowEraseSize = 0000, addrInc = 0004, widthProgram = 0004
2286 1737967039848 GEN4_TO_CONTROLLER_LOG:GEN4_INIT_INT_LOG_ATSAME54P20A DeviceInfo: mask = 0000, exists = false, startAddr = 00000000, endAddr = 00000000, rowSize = 0000, rowEraseSize = 0000, addrInc = 0000, widthProgram = 0000
2286 1737967039848 GEN4_TO_CONTROLLER_LOG:GEN4_INIT_INT_LOG_ATSAME54P20A DeviceInfo: mask = 0000, exists = false, startAddr = 00000000, endAddr = 00000000, rowSize = 0000, rowEraseSize = 0000, addrInc = 0000, widthProgram = 0000
2286 1737967039848 GEN4_TO_CONTROLLER_LOG:GEN4_INIT_INT_LOG_ATSAME54P20A DeviceInfo: mask = ffffffff, exists = true, startAddr = 0080400c, endAddr = 008041ff, rowSize = 0200, rowEraseSize = 0000, addrInc = 0004, widthProgram = 0004
2286 1737967039848 GEN4_TO_CONTROLLER_LOG:GEN4_INIT_INT_LOG_ATSAME54P20A DeviceInfo: mask = 0000, exists = false, startAddr = 00000000, endAddr = 00000000, rowSize = 0000, rowEraseSize = 2000, addrInc = 0000, widthProgram = 0000
2286 1737967039848 GEN4_TO_CONTROLLER_LOG:GEN4_INIT_INT_LOG_ATSAME54P20A DeviceInfo: mask = 0000, exists = false, startAddr = 00000000, endAddr = 00000000, rowSize = 0000, rowEraseSize = 0000, addrInc = 0004, widthProgram = 0004
2286 1737967039848 GEN4_TO_CONTROLLER_LOG:GEN4_INIT_INT_LOG_ATSAME54P20A DeviceInfo: mask = ffffffff, exists = true, startAddr = 03000000, endAddr = e0041fff, rowSize = 0000, rowEraseSize = 0000, addrInc = 0004, widthProgram = 0004
2286 1737967039848 GEN4_TO_CONTROLLER_LOG:GEN4_INIT_INT_LOG_ATSAME54P20A DeviceInfo: mask = 0000, exists = false, startAddr = 00000000, endAddr = 00000000, rowSize = 0000, rowEraseSize = 0000, addrInc = 0000, widthProgram = 0000
2286 1737967039849 GEN4_TO_CONTROLLER_LOG:GEN4_INIT_INT_LOG_ATSAME54P20A DeviceInfo: mask = 0000, exists = false, startAddr = 00000000, endAddr = 00000000, rowSize = 0000, rowEraseSize = 0000, addrInc = 0000, widthProgram = 0000
2286 1737967039849 GEN4_TO_CONTROLLER_LOG:GEN4_INIT_INT_LOG_ATSAME54P20A DeviceInfo: mask = 0000, exists = false, startAddr = 00000000, endAddr = 00000000, rowSize = 0000, rowEraseSize = 0000, addrInc = 0004, widthProgram = 0004
2286 1737967039849 GEN4_TO_CONTROLLER_LOG:GEN4_INIT_INT_LOG_ATSAME54P20A DeviceInfo: mask = 0000, exists = false, startAddr = 00000000, endAddr = 00000000, rowSize = 0000, rowEraseSize = 0000, addrInc = 0004, widthProgram = 0004
2286 1737967039849 GEN4_TO_CONTROLLER_LOG:GEN4_INIT_INT_LOG_ATSAME54P20A DeviceInfo: mask = 0000, exists = false, startAddr = 00000000, endAddr = 00000000, rowSize = 0000, rowEraseSize = 0000, addrInc = 0000, widthProgram = 0000
2286 1737967039849 GEN4_TO_CONTROLLER_LOG:GEN4_INIT_INT_LOG_ATSAME54P20A DeviceInfo: mask = 0000, exists = false, startAddr = 00000000, endAddr = 00000000, rowSize = 0000, rowEraseSize = 0000, addrInc = 0000, widthProgram = 0000
2286 1737967039849 GEN4_TO_CONTROLLER_LOG:GEN4_INIT_INT_LOG_ATSAME54P20A DeviceInfo: mask = 0000, exists = false, startAddr = 00000000, endAddr = 00000000, rowSize = 0000, rowEraseSize = 0000, addrInc = 0000, widthProgram = 0000
2286 1737967039849 GEN4_TO_CONTROLLER_LOG:GEN4_INIT_INT_LOG_ATSAME54P20A DeviceInfo: mask = 0000, exists = false, startAddr = 00000000, endAddr = 00000000, rowSize = 0000, rowEraseSize = 0000, addrInc = 0000, widthProgram = 0000
2286 1737967039849 GEN4_TO_CONTROLLER_LOG:GEN4_INIT_INT_LOG_ATSAME54P20A DeviceInfo: mask = 7fffffff, exists = true, startAddr = 41002018, endAddr = 4100201b, rowSize = 0001, rowEraseSize = 0000, addrInc = 0001, widthProgram = 0001
2286 1737967039849 GEN4_TO_CONTROLLER_LOG:GEN4_INIT_INT_LOG_ATSAME54P20A DeviceInfo: mask = 0000, exists = false, startAddr = 00000000, endAddr = 00000000, rowSize = 0000, rowEraseSize = 0000, addrInc = 0000, widthProgram = 0000
2286 1737967039849 GEN4_TO_CONTROLLER_LOG:GEN4_INIT_INT_LOG_ATSAME54P20A DeviceInfo: mask = 0000, exists = false, startAddr = 00000000, endAddr = 00000000, rowSize = 0000, rowEraseSize = 0000, addrInc = 0000, widthProgram = 0000
2286 1737967039849 GEN4_TO_CONTROLLER_LOG:GEN4_INIT_INT_LOG_ATSAME54P20A DeviceInfo: mask = 0000, exists = false, startAddr = 00000000, endAddr = 00000000, rowSize = 0000, rowEraseSize = 0000, addrInc = 0000, widthProgram = 0000
2286 1737967039849 GEN4_TO_CONTROLLER_LOG:GEN4_INIT_INT_LOG_ATSAME54P20A DeviceInfo: mask = 0000, exists = false, startAddr = 00000000, endAddr = 00000000, rowSize = 0000, rowEraseSize = 0000, addrInc = 0000, widthProgram = 0000
2286 1737967039849 GEN4_TO_CONTROLLER_LOG:GEN4_INIT_INT_LOG_ATSAME54P20A DeviceInfo: mask = 0000, exists = false, startAddr = 00000000, endAddr = 00000000, rowSize = 0000, rowEraseSize = 0000, addrInc = 0000, widthProgram = 0000
2286 1737967039849 GEN4_TO_CONTROLLER_LOG:GEN4_INIT_INT_LOG_ATSAME54P20A DeviceInfo: mask = 0000, exists = false, startAddr = 00000000, endAddr = 00000000, rowSize = 0000, rowEraseSize = 0000, addrInc = 0000, widthProgram = 0000
2286 1737967039849 GEN4_TO_CONTROLLER_LOG:GEN4_INIT_INT_LOG_ATSAME54P20A CfgRequiredBitsMask Values:
2286 1737967039849 GEN4_TO_CONTROLLER_LOG:GEN4_INIT_INT_LOG_ATSAME54P20A Address = 00804000, Mask = 3c007fff
2286 1737967039849 GEN4_TO_CONTROLLER_LOG:GEN4_INIT_INT_LOG_ATSAME54P20A Address = 00804004, Mask = 7fff00ff
2286 1737967039849 GEN4_TO_CONTROLLER_LOG:GEN4_INIT_INT_LOG_ATSAME54P20A Address = 00804008, Mask = ffffffff
2286 1737967039849 GEN4_TO_CONTROLLER_LOG:GEN4_INIT_INT_LOG_ATSAME54P20A BasicInfo: Values:
2286 1737967039849 GEN4_TO_CONTROLLER_LOG:GEN4_INIT_INT_LOG_ATSAME54P20A BasicInfo: InputStream = com.microchip.mplab.libs.toolpacksupport.EquatableFileInputStream@2014eefd, ToolFlavor = PICKit4
2286 1737967039849 GEN4_TO_CONTROLLER_LOG:GEN4_INIT_INT_LOG_ATSAME54P20A Payload End
2286 1737967039849 GEN4_TO_CONTROLLER_LOG:GEN4_INIT_INT_LOG_ATSAME54P20A Post:init
2286 1737967039849 GEN4_TO_CONTROLLER_LOG:GEN4_INIT_INT_LOG_ATSAME54P20A Return Value
2286 1737967039849 GEN4_TO_CONTROLLER_LOG:GEN4_INIT_INT_LOG_ATSAME54P20A none
2286 1737967039849 GEN4_TO_CONTROLLER_LOG:GEN4_INIT_INT_LOG_ATSAME54P20A Return End

2286 1737967039849 GEN4_TO_CONTROLLER_LOG:GEN4_INIT_INT_LOG_ATSAME54P20A Pre:GetInterfaceProvider
2286 1737967039849 GEN4_TO_CONTROLLER_LOG:GEN4_INIT_INT_LOG_ATSAME54P20A Payload
2286 1737967039849 GEN4_TO_CONTROLLER_LOG:GEN4_INIT_INT_LOG_ATSAME54P20A RI4DebugInterface
2286 1737967039849 GEN4_TO_CONTROLLER_LOG:GEN4_INIT_INT_LOG_ATSAME54P20A Payload End
2286 1737967039849 GEN4_TO_CONTROLLER_LOG:GEN4_INIT_INT_LOG_ATSAME54P20A Post:GetInterfaceProvider
2286 1737967039849 GEN4_TO_CONTROLLER_LOG:GEN4_INIT_INT_LOG_ATSAME54P20A Return Value
2286 1737967039849 GEN4_TO_CONTROLLER_LOG:GEN4_INIT_INT_LOG_ATSAME54P20A com.microchip.mplab.libs.RI4ToolsController.implementations.RI4DebugInterfaceImpl@1dc4ef32
2286 1737967039849 GEN4_TO_CONTROLLER_LOG:GEN4_INIT_INT_LOG_ATSAME54P20A Return End

2286 1737967039849 GEN4_TO_CONTROLLER_LOG:GEN4_INIT_INT_LOG_ATSAME54P20A Pre:GetInterfaceProvider
2286 1737967039849 GEN4_TO_CONTROLLER_LOG:GEN4_INIT_INT_LOG_ATSAME54P20A Payload
2286 1737967039849 GEN4_TO_CONTROLLER_LOG:GEN4_INIT_INT_LOG_ATSAME54P20A RI4ProgramInterface
2286 1737967039849 GEN4_TO_CONTROLLER_LOG:GEN4_INIT_INT_LOG_ATSAME54P20A Payload End
2286 1737967039849 GEN4_TO_CONTROLLER_LOG:GEN4_INIT_INT_LOG_ATSAME54P20A Post:GetInterfaceProvider
2286 1737967039849 GEN4_TO_CONTROLLER_LOG:GEN4_INIT_INT_LOG_ATSAME54P20A Return Value
2286 1737967039849 GEN4_TO_CONTROLLER_LOG:GEN4_INIT_INT_LOG_ATSAME54P20A com.microchip.mplab.libs.RI4ToolsController.implementations.RI4ProgramInterfaceImpl@1442de
2286 1737967039849 GEN4_TO_CONTROLLER_LOG:GEN4_INIT_INT_LOG_ATSAME54P20A Return End

2286 1737967039850 GEN4_TO_CONTROLLER_LOG:GEN4_INIT_INT_LOG_ATSAME54P20A Pre:GetInterfaceProvider
2286 1737967039850 GEN4_TO_CONTROLLER_LOG:GEN4_INIT_INT_LOG_ATSAME54P20A Payload
2286 1737967039850 GEN4_TO_CONTROLLER_LOG:GEN4_INIT_INT_LOG_ATSAME54P20A RI4ConnectInterface
2286 1737967039850 GEN4_TO_CONTROLLER_LOG:GEN4_INIT_INT_LOG_ATSAME54P20A Payload End
2286 1737967039850 GEN4_TO_CONTROLLER_LOG:GEN4_INIT_INT_LOG_ATSAME54P20A Post:GetInterfaceProvider
2286 1737967039850 GEN4_TO_CONTROLLER_LOG:GEN4_INIT_INT_LOG_ATSAME54P20A Return Value
2286 1737967039850 GEN4_TO_CONTROLLER_LOG:GEN4_INIT_INT_LOG_ATSAME54P20A com.microchip.mplab.libs.PK4ToolsController.PK4ConnectInterfaceImpl@303e5581
2286 1737967039850 GEN4_TO_CONTROLLER_LOG:GEN4_INIT_INT_LOG_ATSAME54P20A Return End
2286 1737967039850 GEN4_CONNECT_DIAGNOSTICS:acceptablePIDs = [810a, 8109, 810b]
2286 1737967039850 GEN4_CONNECT_DIAGNOSTICS:otherPIDs = [2184]
2286 1737967039850 GEN4_CONNECT_DIAGNOSTICS:Setting selected tool type to pk4
2286 1737967039850 GEN4_CONNECT_DIAGNOSTICS:otherPIDs = [2184]
2286 1737967039850 GEN4_CONNECT_DIAGNOSTICS:acceptablePIDs = [810a, 8109, 810b]

2286 1737967039850 GEN4_TO_CONTROLLER_LOG:GEN4_INIT_INT_LOG_ATSAME54P20A Pre:GetInterfaceProvider
2286 1737967039850 GEN4_TO_CONTROLLER_LOG:GEN4_INIT_INT_LOG_ATSAME54P20A Payload
2286 1737967039850 GEN4_TO_CONTROLLER_LOG:GEN4_INIT_INT_LOG_ATSAME54P20A RI4ControllerDiagnosticsInterface
2286 1737967039850 GEN4_TO_CONTROLLER_LOG:GEN4_INIT_INT_LOG_ATSAME54P20A Payload End
2286 1737967039850 GEN4_TO_CONTROLLER_LOG:GEN4_INIT_INT_LOG_ATSAME54P20A Post:GetInterfaceProvider
2286 1737967039850 GEN4_TO_CONTROLLER_LOG:GEN4_INIT_INT_LOG_ATSAME54P20A Return Value
2286 1737967039850 GEN4_TO_CONTROLLER_LOG:GEN4_INIT_INT_LOG_ATSAME54P20A com.microchip.mplab.libs.RI4ToolsController.implementations.RI4ControllerDiagnosticsInterfaceImpl@c23ddbf
2286 1737967039850 GEN4_TO_CONTROLLER_LOG:GEN4_INIT_INT_LOG_ATSAME54P20A Return End

2286 1737967039850 GEN4_TO_CONTROLLER_LOG:GEN4_INIT_INT_LOG_ATSAME54P20A Pre:GetInterfaceProvider
2286 1737967039850 GEN4_TO_CONTROLLER_LOG:GEN4_INIT_INT_LOG_ATSAME54P20A Payload
2286 1737967039850 GEN4_TO_CONTROLLER_LOG:GEN4_INIT_INT_LOG_ATSAME54P20A ProgrammerToGo
2286 1737967039850 GEN4_TO_CONTROLLER_LOG:GEN4_INIT_INT_LOG_ATSAME54P20A Payload End
2286 1737967039850 GEN4_TO_CONTROLLER_LOG:GEN4_INIT_INT_LOG_ATSAME54P20A Post:GetInterfaceProvider
2286 1737967039850 GEN4_TO_CONTROLLER_LOG:GEN4_INIT_INT_LOG_ATSAME54P20A Return Value
2286 1737967039850 GEN4_TO_CONTROLLER_LOG:GEN4_INIT_INT_LOG_ATSAME54P20A com.microchip.mplab.libs.RI4ToolsController.implementations.ProgrammerToGoImpl@36240e76
2286 1737967039850 GEN4_TO_CONTROLLER_LOG:GEN4_INIT_INT_LOG_ATSAME54P20A Return End

2286 1737967039850 GEN4_TO_CONTROLLER_LOG:GEN4_INIT_INT_LOG_ATSAME54P20A Pre:GetInterfaceProvider
2286 1737967039850 GEN4_TO_CONTROLLER_LOG:GEN4_INIT_INT_LOG_ATSAME54P20A Payload
2286 1737967039850 GEN4_TO_CONTROLLER_LOG:GEN4_INIT_INT_LOG_ATSAME54P20A Status
2286 1737967039850 GEN4_TO_CONTROLLER_LOG:GEN4_INIT_INT_LOG_ATSAME54P20A Payload End
2286 1737967039850 GEN4_TO_CONTROLLER_LOG:GEN4_INIT_INT_LOG_ATSAME54P20A Post:GetInterfaceProvider
2286 1737967039850 GEN4_TO_CONTROLLER_LOG:GEN4_INIT_INT_LOG_ATSAME54P20A Return Value
2286 1737967039850 GEN4_TO_CONTROLLER_LOG:GEN4_INIT_INT_LOG_ATSAME54P20A null
2286 1737967039850 GEN4_TO_CONTROLLER_LOG:GEN4_INIT_INT_LOG_ATSAME54P20A Return End
2286 1737967039918 GEN4_CONNECT_DIAGNOSTICS:ENTERING: com.microchip.mplab.mdbcore.RI4Tool.ConnectionHandler.CheckForFWUpdates()
2286 1737967039918 GEN4_CONNECT_DIAGNOSTICS:Created FirmwareUpdateHandler com.microchip.mplab.mdbcore.pk4hybrid.pk4hybridFirmwareUpdateHandler@1484b8de
2286 1737967039918 GEN4_CONNECT_DIAGNOSTICS:ENTERING: com.microchip.mplab.mdbcore.pk4hybrid.pk4hybridFirmwareUpdateHandler.UpdateFirmware(FirmwareInfo, UpdateMessage)
2286 1737967039918 GEN4_CONNECT_DIAGNOSTICS:areWeInBoot returned false
2286 1737967039918 GEN4_CONNECT_DIAGNOSTICS:inBoot = false
2286 1737967039918 GEN4_CONNECT_DIAGNOSTICS:uMode = checkingVersions
2286 1737967039918 GEN4_CONNECT_DIAGNOSTICS:selectedTool = pk4
2286 1737967039918 GEN4_CONNECT_DIAGNOSTICS:current toolType = pk4
2286 1737967039918 GEN4_CONNECT_DIAGNOSTICS:current tool mode = pk4
2286 1737967039918 GEN4_CONNECT_DIAGNOSTICS:ENTERING: com.microchip.mplab.mdbcore.pk4hybrid.pk4hybridFirmwareUpdateHandler.GetUpdateInfo()
2286 1737967039919 GEN4_CONNECT_DIAGNOSTICS:Parsing file  for firmware updates
2286 1737967039919 GEN4_CONNECT_DIAGNOSTICS:ENTERING: com.microchip.mplab.mdbcore.pk4hybrid.pk4hybridFirmwareUpdateHandler.ParseSelectedVersionsFromJamFile()
2286 1737967039919 GEN4_CONNECT_DIAGNOSTICS:Jame file line = pkob4_boot.hex,010141
2286 1737967039919 GEN4_CONNECT_DIAGNOSTICS:Jame file line = scripts.xml,000873
2286 1737967039919 GEN4_CONNECT_DIAGNOSTICS:Jame file line = pkob4_app1 000908, 0040C000
2286 1737967039919 GEN4_CONNECT_DIAGNOSTICS:EXITING: com.microchip.mplab.mdbcore.pk4hybrid.pk4hybridFirmwareUpdateHandler.ri4ParseSelectedVersionsFromJamFile()
2286 1737967039919 GEN4_CONNECT_DIAGNOSTICS:EXITING: com.microchip.mplab.mdbcore.pk4hybrid.pk4hybridFirmwareUpdateHandler.GetUpdateInfo()
2286 1737967039919 GEN4_CONNECT_DIAGNOSTICS:current toolType = pk4

2286 1737967039919 GEN4_TO_CONTROLLER_LOG:GEN4_CONNECT_INT_LOG_ATSAME54P20A Pre:EstablishCommunincations
2286 1737967039919 GEN4_TO_CONTROLLER_LOG:GEN4_CONNECT_INT_LOG_ATSAME54P20A Payload
2286 1737967039919 GEN4_TO_CONTROLLER_LOG:GEN4_CONNECT_INT_LOG_ATSAME54P20A com.microchip.mplab.mdbcore.PK4Tool.PK4Com@65410621
2286 1737967039919 GEN4_TO_CONTROLLER_LOG:GEN4_CONNECT_INT_LOG_ATSAME54P20A Payload End
2286 1737967039919 GEN4_TO_CONTROLLER_LOG:GEN4_CONNECT_INT_LOG_ATSAME54P20A Post:EstablishCommunincations
2286 1737967039919 GEN4_TO_CONTROLLER_LOG:GEN4_CONNECT_INT_LOG_ATSAME54P20A Return Value
2286 1737967039919 GEN4_TO_CONTROLLER_LOG:GEN4_CONNECT_INT_LOG_ATSAME54P20A true
2286 1737967039919 GEN4_TO_CONTROLLER_LOG:GEN4_CONNECT_INT_LOG_ATSAME54P20A Return End

2286 1737967039919 GEN4_TO_CONTROLLER_LOG:GEN4_CONNECT_INT_LOG_ATSAME54P20A Pre:GetFirmwareInfo
2286 1737967039919 GEN4_TO_CONTROLLER_LOG:GEN4_CONNECT_INT_LOG_ATSAME54P20A Payload
2286 1737967039919 GEN4_TO_CONTROLLER_LOG:GEN4_CONNECT_INT_LOG_ATSAME54P20A null
2286 1737967039919 GEN4_TO_CONTROLLER_LOG:GEN4_CONNECT_INT_LOG_ATSAME54P20A Payload End
2286 1737967039927 GEN4_TO_CONTROLLER_LOG:GEN4_CONNECT_INT_LOG_ATSAME54P20A Post:GetFirmwareInfo
2286 1737967039927 GEN4_TO_CONTROLLER_LOG:GEN4_CONNECT_INT_LOG_ATSAME54P20A Return Value
2286 1737967039927 GEN4_TO_CONTROLLER_LOG:GEN4_CONNECT_INT_LOG_ATSAME54P20A FirmwareInfo: Values:
2286 1737967039928 GEN4_TO_CONTROLLER_LOG:GEN4_CONNECT_INT_LOG_ATSAME54P20A FirmwareInfo: boot = false, bootVer = 01.01.41, apVer = 00.09.08, fpgaVer = ff.ff.ff, scriptVer = 00.08.73, macAddress = 0495683578451535048485252484953, devID = a1020e01, devID1 = 1, devSN0 = ffffffff, devSN1 = ffffffff, serialNumber = 020012202RYN000072, appCommitID = null, scriptCommitID = df19a696ae, PCB_ID = 80000000
2286 1737967039928 GEN4_TO_CONTROLLER_LOG:GEN4_CONNECT_INT_LOG_ATSAME54P20A Return End
2286 1737967039972 GEN4_CONNECT_DIAGNOSTICS:appNeedsUpdate returned false
2286 1737967039972 GEN4_CONNECT_DIAGNOSTICS:EXITING: com.microchip.mplab.mdbcore.RI4Tool.ConnectionHandler.CheckForFWUpdates()

2286 1737967039972 GEN4_TO_CONTROLLER_LOG:GEN4_CONNECT_INT_LOG_ATSAME54P20A Pre:EstablishCommunincations
2286 1737967039972 GEN4_TO_CONTROLLER_LOG:GEN4_CONNECT_INT_LOG_ATSAME54P20A Payload
2286 1737967039972 GEN4_TO_CONTROLLER_LOG:GEN4_CONNECT_INT_LOG_ATSAME54P20A com.microchip.mplab.mdbcore.PK4Tool.PK4Com@65410621
2286 1737967039972 GEN4_TO_CONTROLLER_LOG:GEN4_CONNECT_INT_LOG_ATSAME54P20A Payload End
2286 1737967039972 GEN4_TO_CONTROLLER_LOG:GEN4_CONNECT_INT_LOG_ATSAME54P20A Post:EstablishCommunincations
2286 1737967039972 GEN4_TO_CONTROLLER_LOG:GEN4_CONNECT_INT_LOG_ATSAME54P20A Return Value
2286 1737967039972 GEN4_TO_CONTROLLER_LOG:GEN4_CONNECT_INT_LOG_ATSAME54P20A true
2286 1737967039972 GEN4_TO_CONTROLLER_LOG:GEN4_CONNECT_INT_LOG_ATSAME54P20A Return End

2286 1737967039972 GEN4_TO_CONTROLLER_LOG:GEN4_CONNECT_INT_LOG_ATSAME54P20A Pre:GetFirmwareInfo
2286 1737967039972 GEN4_TO_CONTROLLER_LOG:GEN4_CONNECT_INT_LOG_ATSAME54P20A Payload
2286 1737967039972 GEN4_TO_CONTROLLER_LOG:GEN4_CONNECT_INT_LOG_ATSAME54P20A null
2286 1737967039972 GEN4_TO_CONTROLLER_LOG:GEN4_CONNECT_INT_LOG_ATSAME54P20A Payload End
2286 1737967039981 GEN4_TO_CONTROLLER_LOG:GEN4_CONNECT_INT_LOG_ATSAME54P20A Post:GetFirmwareInfo
2286 1737967039981 GEN4_TO_CONTROLLER_LOG:GEN4_CONNECT_INT_LOG_ATSAME54P20A Return Value
2286 1737967039981 GEN4_TO_CONTROLLER_LOG:GEN4_CONNECT_INT_LOG_ATSAME54P20A FirmwareInfo: Values:
2286 1737967039981 GEN4_TO_CONTROLLER_LOG:GEN4_CONNECT_INT_LOG_ATSAME54P20A FirmwareInfo: boot = false, bootVer = 01.01.41, apVer = 00.09.08, fpgaVer = ff.ff.ff, scriptVer = 00.08.73, macAddress = 0495683578451535048485252484953, devID = a1020e01, devID1 = 1, devSN0 = ffffffff, devSN1 = ffffffff, serialNumber = 020012202RYN000072, appCommitID = null, scriptCommitID = df19a696ae, PCB_ID = 80000000
2286 1737967039981 GEN4_TO_CONTROLLER_LOG:GEN4_CONNECT_INT_LOG_ATSAME54P20A Return End

2286 1737967039981 GEN4_TO_CONTROLLER_LOG:GEN4_CONNECT_INT_LOG_ATSAME54P20A Pre:GetFirmwareInfo
2286 1737967039981 GEN4_TO_CONTROLLER_LOG:GEN4_CONNECT_INT_LOG_ATSAME54P20A Payload
2286 1737967039981 GEN4_TO_CONTROLLER_LOG:GEN4_CONNECT_INT_LOG_ATSAME54P20A null
2286 1737967039981 GEN4_TO_CONTROLLER_LOG:GEN4_CONNECT_INT_LOG_ATSAME54P20A Payload End
2286 1737967039989 GEN4_TO_CONTROLLER_LOG:GEN4_CONNECT_INT_LOG_ATSAME54P20A Post:GetFirmwareInfo
2286 1737967039989 GEN4_TO_CONTROLLER_LOG:GEN4_CONNECT_INT_LOG_ATSAME54P20A Return Value
2286 1737967039989 GEN4_TO_CONTROLLER_LOG:GEN4_CONNECT_INT_LOG_ATSAME54P20A FirmwareInfo: Values:
2286 1737967039989 GEN4_TO_CONTROLLER_LOG:GEN4_CONNECT_INT_LOG_ATSAME54P20A FirmwareInfo: boot = false, bootVer = 01.01.41, apVer = 00.09.08, fpgaVer = ff.ff.ff, scriptVer = 00.08.73, macAddress = 0495683578451535048485252484953, devID = a1020e01, devID1 = 1, devSN0 = ffffffff, devSN1 = ffffffff, serialNumber = 020012202RYN000072, appCommitID = null, scriptCommitID = df19a696ae, PCB_ID = 80000000
2286 1737967039989 GEN4_TO_CONTROLLER_LOG:GEN4_CONNECT_INT_LOG_ATSAME54P20A Return End
2286 1737967039989 GEN4_CONNECT_DIAGNOSTICS:ENTERING: com.microchip.mplab.mdbcore.RI4Tool.ConnectionHandler.CheckForFWUpdates()
2286 1737967039989 GEN4_CONNECT_DIAGNOSTICS:Created FirmwareUpdateHandler com.microchip.mplab.mdbcore.pk4hybrid.pk4hybridFirmwareUpdateHandler@1484b8de
2286 1737967039990 GEN4_CONNECT_DIAGNOSTICS:ENTERING: com.microchip.mplab.mdbcore.pk4hybrid.pk4hybridFirmwareUpdateHandler.UpdateFirmware(FirmwareInfo, UpdateMessage)
2286 1737967039990 GEN4_CONNECT_DIAGNOSTICS:areWeInBoot returned false
2286 1737967039990 GEN4_CONNECT_DIAGNOSTICS:inBoot = false
2286 1737967039990 GEN4_CONNECT_DIAGNOSTICS:uMode = done
2286 1737967039990 GEN4_CONNECT_DIAGNOSTICS:selectedTool = pk4
2286 1737967039990 GEN4_CONNECT_DIAGNOSTICS:current toolType = pk4
2286 1737967039990 GEN4_CONNECT_DIAGNOSTICS:current tool mode = pk4
2286 1737967039990 GEN4_CONNECT_DIAGNOSTICS:ENTERING: com.microchip.mplab.mdbcore.pk4hybrid.pk4hybridFirmwareUpdateHandler.updatePk4HybridFirmware()
2286 1737967039990 GEN4_CONNECT_DIAGNOSTICS:Don't upgrade fimware = false
2286 1737967039990 GEN4_CONNECT_DIAGNOSTICS:ENTERING: com.microchip.mplab.mdbcore.pk4hybrid.pk4hybridFirmwareUpdateHandler.updatePk4HybridFirmware()
2286 1737967039990 GEN4_CONNECT_DIAGNOSTICS:EXITING: com.microchip.mplab.mdbcore.pk4hybrid.pk4hybridFirmwareUpdateHandler.UpdateFirmware(FirmwareInfo, UpdateMessage)
2286 1737967039990 GEN4_CONNECT_DIAGNOSTICS:EXITING: com.microchip.mplab.mdbcore.RI4Tool.ConnectionHandler.CheckForFWUpdates()

2286 1737967039990 GEN4_TO_CONTROLLER_LOG:GEN4_CONNECT_INT_LOG_ATSAME54P20A Pre:SetPowerInfo
2286 1737967039990 GEN4_TO_CONTROLLER_LOG:GEN4_CONNECT_INT_LOG_ATSAME54P20A Payload
2286 1737967039990 GEN4_TO_CONTROLLER_LOG:GEN4_CONNECT_INT_LOG_ATSAME54P20A PowerInfo: Values:
2286 1737967039990 GEN4_TO_CONTROLLER_LOG:GEN4_CONNECT_INT_LOG_ATSAME54P20A PowerInfo: shotDownSystem = false, isToolPower = false, voltage = 3.300000, useVppFirst = false, useLowVoltageProgramming = true, useMaintainActivePower = false
2286 1737967039990 GEN4_TO_CONTROLLER_LOG:GEN4_CONNECT_INT_LOG_ATSAME54P20A Payload End
2286 1737967039990 XXXX 1737967039990, Thread 2286: XXXX 1737967039990, Entering Thread 2286: Commands::runScriptBasic with script contents. contents[0] = 0x39, ...  
2286 1737967039992 XXXX 1737967039992, Thread 2286: XXXX 1737967039992, Exiting Thread 2286: Commands::runScriptBasic  
2286 1737967039992 XXXX 1737967039992, Thread 2286: XXXX 1737967039992, Entering Thread 2286: Commands::runScriptBasic with script contents. contents[0] = 0x46, ...  
2286 1737967039993 XXXX 1737967039993, Thread 2286: XXXX 1737967039993, Exiting Thread 2286: Commands::runScriptBasic  
2286 1737967039993 XXXX 1737967039993, Thread 2286: XXXX 1737967039993, Entering Thread 2286: Commands::runScriptBasic with script contents. contents[0] = 0x44, ...  
2286 1737967039994 XXXX 1737967039994, Thread 2286: XXXX 1737967039994, Exiting Thread 2286: Commands::runScriptBasic  
2286 1737967039994 XXXX 1737967039994, Thread 2286: XXXX 1737967039994, Entering Thread 2286: Commands::runScriptBasic with script contents. contents[0] = 0xef, ...  
2286 1737967039996 XXXX 1737967039996, Thread 2286: XXXX 1737967039996, Exiting Thread 2286: Commands::runScriptBasic  
2286 1737967039996 XXXX 1737967039996, Thread 2286: XXXX 1737967039996, Entering Thread 2286: Commands::runScriptBasic with script contents. contents[0] = 0x40, ...  
2286 1737967039997 XXXX 1737967039997, Thread 2286: XXXX 1737967039997, Exiting Thread 2286: Commands::runScriptBasic  
2286 1737967039997 XXXX 1737967039997, Thread 2286: XXXX 1737967039997, Entering Thread 2286: Commands::runScriptBasic with script contents. contents[0] = 0x47, ...  
2286 1737967039998 XXXX 1737967039998, Thread 2286: XXXX 1737967039998, Exiting Thread 2286: Commands::runScriptBasic  
2286 1737967039998 GEN4_TO_CONTROLLER_LOG:GEN4_CONNECT_INT_LOG_ATSAME54P20A Post:SetPowerInfo
2286 1737967039998 GEN4_TO_CONTROLLER_LOG:GEN4_CONNECT_INT_LOG_ATSAME54P20A Return Value
2286 1737967039998 GEN4_TO_CONTROLLER_LOG:GEN4_CONNECT_INT_LOG_ATSAME54P20A none
2286 1737967039998 GEN4_TO_CONTROLLER_LOG:GEN4_CONNECT_INT_LOG_ATSAME54P20A Return End

2286 1737967039998 GEN4_TO_CONTROLLER_LOG:GEN4_CONNECT_INT_LOG_ATSAME54P20A Pre:GetVoltageInfo
2286 1737967039998 GEN4_TO_CONTROLLER_LOG:GEN4_CONNECT_INT_LOG_ATSAME54P20A Payload
2286 1737967039998 GEN4_TO_CONTROLLER_LOG:GEN4_CONNECT_INT_LOG_ATSAME54P20A null
2286 1737967039998 GEN4_TO_CONTROLLER_LOG:GEN4_CONNECT_INT_LOG_ATSAME54P20A Payload End
2286 1737967039998 XXXX 1737967039998, Thread 2286: XXXX 1737967039998, Entering Thread 2286: Commands::runScriptBasic with script contents. contents[0] = 0x47, ...  
2286 1737967039999 XXXX 1737967039999, Thread 2286: XXXX 1737967039999, Exiting Thread 2286: Commands::runScriptBasic  
2286 1737967039999 GEN4_TO_CONTROLLER_LOG:GEN4_CONNECT_INT_LOG_ATSAME54P20A Post:GetVoltageInfo
2286 1737967039999 GEN4_TO_CONTROLLER_LOG:GEN4_CONNECT_INT_LOG_ATSAME54P20A Return Value
2286 1737967039999 GEN4_TO_CONTROLLER_LOG:GEN4_CONNECT_INT_LOG_ATSAME54P20A VoltagesInfo: Values:
2286 1737967039999 GEN4_TO_CONTROLLER_LOG:GEN4_CONNECT_INT_LOG_ATSAME54P20A VoltagesInfo: internalVdd = 3300, internalVpp = 3300, targetVdd = 3300, targetVpp = 3300, vddSense = 3300, temp = 25000, vddCurrentSense = 0, vddVoltageSense = 3300
2286 1737967039999 GEN4_TO_CONTROLLER_LOG:GEN4_CONNECT_INT_LOG_ATSAME54P20A Return End

2286 1737967039999 GEN4_TO_CONTROLLER_LOG:GEN4_CONNECT_INT_LOG_ATSAME54P20A Pre:GetFirmwareInfo
2286 1737967039999 GEN4_TO_CONTROLLER_LOG:GEN4_CONNECT_INT_LOG_ATSAME54P20A Payload
2286 1737967039999 GEN4_TO_CONTROLLER_LOG:GEN4_CONNECT_INT_LOG_ATSAME54P20A null
2286 1737967039999 GEN4_TO_CONTROLLER_LOG:GEN4_CONNECT_INT_LOG_ATSAME54P20A Payload End
2286 1737967040007 GEN4_TO_CONTROLLER_LOG:GEN4_CONNECT_INT_LOG_ATSAME54P20A Post:GetFirmwareInfo
2286 1737967040007 GEN4_TO_CONTROLLER_LOG:GEN4_CONNECT_INT_LOG_ATSAME54P20A Return Value
2286 1737967040007 GEN4_TO_CONTROLLER_LOG:GEN4_CONNECT_INT_LOG_ATSAME54P20A FirmwareInfo: Values:
2286 1737967040007 GEN4_TO_CONTROLLER_LOG:GEN4_CONNECT_INT_LOG_ATSAME54P20A FirmwareInfo: boot = false, bootVer = 01.01.41, apVer = 00.09.08, fpgaVer = ff.ff.ff, scriptVer = 00.08.73, macAddress = 0495683578451535048485252484953, devID = a1020e01, devID1 = 1, devSN0 = ffffffff, devSN1 = ffffffff, serialNumber = 020012202RYN000072, appCommitID = null, scriptCommitID = df19a696ae, PCB_ID = 80000000
2286 1737967040007 GEN4_TO_CONTROLLER_LOG:GEN4_CONNECT_INT_LOG_ATSAME54P20A Return End

2286 1737967040007 GEN4_TO_CONTROLLER_LOG:GEN4_CONNECT_INT_LOG_ATSAME54P20A Pre:SetToolInfo
2286 1737967040007 GEN4_TO_CONTROLLER_LOG:GEN4_CONNECT_INT_LOG_ATSAME54P20A Payload
2286 1737967040007 GEN4_TO_CONTROLLER_LOG:GEN4_CONNECT_INT_LOG_ATSAME54P20A ToolInfo: Values:
2286 1737967040007 GEN4_TO_CONTROLLER_LOG:GEN4_CONNECT_INT_LOG_ATSAME54P20A ToolInfo: speedLevel = 1, PGCResistance = 4700, PGDResistance = 4700, PGCPullDir = None, PGDPullDir = None, ICSPSelected = Wire2
2286 1737967040007 GEN4_TO_CONTROLLER_LOG:GEN4_CONNECT_INT_LOG_ATSAME54P20A Payload End
2286 1737967040007 XXXX 1737967040007, Thread 2286: XXXX 1737967040007, Entering Thread 2286: Commands::runScriptBasic with script contents. contents[0] = 0x27, ...  
2286 1737967040155 XXXX 1737967040155, Thread 2286: XXXX 1737967040155, Exiting Thread 2286: Commands::runScriptBasic  
2286 1737967040155 XXXX 1737967040155, Thread 2286: XXXX 1737967040155, Entering Thread 2286: Commands::runScriptBasic, script name = SetSpeedFromDevice, timeOut = -1 ms  
2286 1737967040155 XXXX 1737967040155, Thread 2286: XXXX 1737967040155, Exiting Thread 2286: Commands::runScriptBasic  
2286 1737967040155 XXXX 1737967040155, Thread 2286: XXXX 1737967040155, Entering Thread 2286: Commands::runScriptBasic with script contents. contents[0] = 0xed, ...  
2286 1737967040156 XXXX 1737967040156, Thread 2286: XXXX 1737967040156, Exiting Thread 2286: Commands::runScriptBasic  
2286 1737967040156 XXXX 1737967040156, Thread 2286: XXXX 1737967040156, Entering Thread 2286: Commands::runScriptBasic with script contents. contents[0] = 0x3b, ...  
2286 1737967040157 XXXX 1737967040157, Thread 2286: XXXX 1737967040157, Exiting Thread 2286: Commands::runScriptBasic  
2286 1737967040157 XXXX 1737967040157, Thread 2286: XXXX 1737967040157, Entering Thread 2286: Commands::runScriptBasic with script contents. contents[0] = 0xd4, ...  
2286 1737967040158 XXXX 1737967040158, Thread 2286: XXXX 1737967040158, Exiting Thread 2286: Commands::runScriptBasic  
2286 1737967040158 GEN4_TO_CONTROLLER_LOG:GEN4_CONNECT_INT_LOG_ATSAME54P20A Post:SetToolInfo
2286 1737967040158 GEN4_TO_CONTROLLER_LOG:GEN4_CONNECT_INT_LOG_ATSAME54P20A Return Value
2286 1737967040158 GEN4_TO_CONTROLLER_LOG:GEN4_CONNECT_INT_LOG_ATSAME54P20A none
2286 1737967040158 GEN4_TO_CONTROLLER_LOG:GEN4_CONNECT_INT_LOG_ATSAME54P20A Return End

2286 1737967040166 GEN4_TO_CONTROLLER_LOG:GEN4_CONNECT_INT_LOG_ATSAME54P20A Pre:GetTargetIDInfo
2286 1737967040166 GEN4_TO_CONTROLLER_LOG:GEN4_CONNECT_INT_LOG_ATSAME54P20A Payload
2286 1737967040166 GEN4_TO_CONTROLLER_LOG:GEN4_CONNECT_INT_LOG_ATSAME54P20A null
2286 1737967040166 GEN4_TO_CONTROLLER_LOG:GEN4_CONNECT_INT_LOG_ATSAME54P20A Payload End
2286 1737967040167 XXXX 1737967040167, Thread 2286: XXXX 1737967040167, Entering Thread 2286: Commands::runScriptBasic, script name = InitSWD, timeOut = -1 ms  
2286 1737967040183 XXXX 1737967040183, Thread 2286: XXXX 1737967040183, Exiting Thread 2286: Commands::runScriptBasic  
2286 1737967040183 XXXX 1737967040183, Thread 2286: XXXX 1737967040183, Entering Thread 2286: Commands::runScriptBasic, script name = GetDeviceID, timeOut = -1 ms  
2286 1737967040185 XXXX 1737967040185, Thread 2286: XXXX 1737967040185, Exiting Thread 2286: Commands::runScriptBasic  
2286 1737967040185 GEN4_TO_CONTROLLER_LOG:GEN4_CONNECT_INT_LOG_ATSAME54P20A Post:GetTargetIDInfo
2286 1737967040185 GEN4_TO_CONTROLLER_LOG:GEN4_CONNECT_INT_LOG_ATSAME54P20A Return Value
2286 1737967040185 GEN4_TO_CONTROLLER_LOG:GEN4_CONNECT_INT_LOG_ATSAME54P20A TargetIDInfo: Values:
2286 1737967040185 GEN4_TO_CONTROLLER_LOG:GEN4_CONNECT_INT_LOG_ATSAME54P20A TargetIDInfo: DeviceID = 61840000
2286 1737967040185 GEN4_TO_CONTROLLER_LOG:GEN4_CONNECT_INT_LOG_ATSAME54P20A Return End

2286 1737967040386 GEN4_TO_CONTROLLER_LOG:GEN4_PROGRAM_INT_LOG_ATSAME54P20A Pre:SendOperation
2286 1737967040386 GEN4_TO_CONTROLLER_LOG:GEN4_PROGRAM_INT_LOG_ATSAME54P20A Payload
2286 1737967040386 GEN4_TO_CONTROLLER_LOG:GEN4_PROGRAM_INT_LOG_ATSAME54P20A OperationInfo: Values:
2286 1737967040386 GEN4_TO_CONTROLLER_LOG:GEN4_PROGRAM_INT_LOG_ATSAME54P20A OperationInfo: Type = erase, Mask = 00000000, Erase = false, Production Mode = true
2286 1737967040386 GEN4_TO_CONTROLLER_LOG:GEN4_PROGRAM_INT_LOG_ATSAME54P20A TransferInfo: Start = 0, End = fffff, Buffer Length = 0, Type = Pgm, Mask = 00000000
2286 1737967040386 GEN4_TO_CONTROLLER_LOG:GEN4_PROGRAM_INT_LOG_ATSAME54P20A TransferInfo: Start = 4000000, End = 4ffffff, Buffer Length = 0, Type = Pgm, Mask = 00000000
2286 1737967040386 GEN4_TO_CONTROLLER_LOG:GEN4_PROGRAM_INT_LOG_ATSAME54P20A TransferInfo: Start = 804000, End = 80400b, Buffer Length = 0, Type = Cfg, Mask = 00000000
2286 1737967040386 GEN4_TO_CONTROLLER_LOG:GEN4_PROGRAM_INT_LOG_ATSAME54P20A TransferInfo: Start = 80400c, End = 8041ff, Buffer Length = 0, Type = UserID, Mask = 00000000
2286 1737967040386 GEN4_TO_CONTROLLER_LOG:GEN4_PROGRAM_INT_LOG_ATSAME54P20A TransferInfo: Start = 20000000, End = 2003ffff, Buffer Length = 0, Type = FileRegs, Mask = 00000000
2286 1737967040386 GEN4_TO_CONTROLLER_LOG:GEN4_PROGRAM_INT_LOG_ATSAME54P20A TransferInfo: Start = 47000000, End = 47001fff, Buffer Length = 0, Type = FileRegs, Mask = 00000000
2286 1737967040386 GEN4_TO_CONTROLLER_LOG:GEN4_PROGRAM_INT_LOG_ATSAME54P20A Payload End
2286 1737967040386 XXXX 1737967040386, Thread 2286: XXXX 1737967040386, Entering Thread 2286: Commands::runScriptBasic, script name = EraseChip, timeOut = -1 ms  
2286 1737967045318 XXXX 1737967045318, Thread 2286: XXXX 1737967045318, Exiting Thread 2286: Commands::runScriptBasic  
2286 1737967045318 GEN4_TO_CONTROLLER_LOG:GEN4_PROGRAM_INT_LOG_ATSAME54P20A Post:SendOperation
2286 1737967045318 GEN4_TO_CONTROLLER_LOG:GEN4_PROGRAM_INT_LOG_ATSAME54P20A Return Value
2286 1737967045318 GEN4_TO_CONTROLLER_LOG:GEN4_PROGRAM_INT_LOG_ATSAME54P20A None
2286 1737967045318 GEN4_TO_CONTROLLER_LOG:GEN4_PROGRAM_INT_LOG_ATSAME54P20A Return End

2286 1737967045373 GEN4_TO_CONTROLLER_LOG:GEN4_PROGRAM_INT_LOG_ATSAME54P20A Pre:SendOperation
2286 1737967045373 GEN4_TO_CONTROLLER_LOG:GEN4_PROGRAM_INT_LOG_ATSAME54P20A Payload
2286 1737967045373 GEN4_TO_CONTROLLER_LOG:GEN4_PROGRAM_INT_LOG_ATSAME54P20A OperationInfo: Values:
2286 1737967045373 GEN4_TO_CONTROLLER_LOG:GEN4_PROGRAM_INT_LOG_ATSAME54P20A OperationInfo: Type = read, Mask = 00000000, Erase = false, Production Mode = true
2286 1737967045373 GEN4_TO_CONTROLLER_LOG:GEN4_PROGRAM_INT_LOG_ATSAME54P20A TransferInfo: Start = 804000, End = 8041ff, Buffer Length = 512, Type = Cfg, Mask = 00000002
2286 1737967045373 GEN4_TO_CONTROLLER_LOG:GEN4_PROGRAM_INT_LOG_ATSAME54P20A Payload End
2286 1737967045373 XXXX 1737967045373, Thread 2286: XXXX 1737967045373, Entering Thread 2286: Commands::runScriptWithUpload, script name = ReadConfigmem  
2286 1737967045373 XXXX 1737967045373, Thread 2286: XXXX 1737967045373, Entering Thread 2286: ToolCommUsb::readTransfer, sideData is 0x24 bytes long, transferDataLength is 0x200 bytes long  
2286 1737967045631 XXXX 1737967045631, Thread 2286: XXXX 1737967045631, Exiting Thread 2286: ToolCommUsb::readTransfer,  cr.status = 0x0  
2286 1737967045631 XXXX 1737967045631, Thread 2286: XXXX 1737967045631, Exiting Thread 2286: Commands::runScriptWithUpload  
2286 1737967045631 GEN4_TO_CONTROLLER_LOG:GEN4_PROGRAM_INT_LOG_ATSAME54P20A Post:SendOperation
2286 1737967045631 GEN4_TO_CONTROLLER_LOG:GEN4_PROGRAM_INT_LOG_ATSAME54P20A Return Value
2286 1737967045631 GEN4_TO_CONTROLLER_LOG:GEN4_PROGRAM_INT_LOG_ATSAME54P20A None
2286 1737967045631 GEN4_TO_CONTROLLER_LOG:GEN4_PROGRAM_INT_LOG_ATSAME54P20A Return End

2286 1737967045631 GEN4_TO_CONTROLLER_LOG:GEN4_PROGRAM_INT_LOG_ATSAME54P20A Pre:SendOperation
2286 1737967045631 GEN4_TO_CONTROLLER_LOG:GEN4_PROGRAM_INT_LOG_ATSAME54P20A Payload
2286 1737967045631 GEN4_TO_CONTROLLER_LOG:GEN4_PROGRAM_INT_LOG_ATSAME54P20A OperationInfo: Values:
2286 1737967045631 GEN4_TO_CONTROLLER_LOG:GEN4_PROGRAM_INT_LOG_ATSAME54P20A OperationInfo: Type = read, Mask = 00000000, Erase = false, Production Mode = true
2286 1737967045631 GEN4_TO_CONTROLLER_LOG:GEN4_PROGRAM_INT_LOG_ATSAME54P20A Payload End
2286 1737967045631 GEN4_TO_CONTROLLER_LOG:GEN4_PROGRAM_INT_LOG_ATSAME54P20A Post:SendOperation
2286 1737967045631 GEN4_TO_CONTROLLER_LOG:GEN4_PROGRAM_INT_LOG_ATSAME54P20A Return Value
2286 1737967045631 GEN4_TO_CONTROLLER_LOG:GEN4_PROGRAM_INT_LOG_ATSAME54P20A None
2286 1737967045631 GEN4_TO_CONTROLLER_LOG:GEN4_PROGRAM_INT_LOG_ATSAME54P20A Return End

2286 1737967045637 GEN4_TO_CONTROLLER_LOG:GEN4_PROGRAM_INT_LOG_ATSAME54P20A Pre:SendOperation
2286 1737967045637 GEN4_TO_CONTROLLER_LOG:GEN4_PROGRAM_INT_LOG_ATSAME54P20A Payload
2286 1737967045637 GEN4_TO_CONTROLLER_LOG:GEN4_PROGRAM_INT_LOG_ATSAME54P20A OperationInfo: Values:
2286 1737967045637 GEN4_TO_CONTROLLER_LOG:GEN4_PROGRAM_INT_LOG_ATSAME54P20A OperationInfo: Type = read, Mask = 00000000, Erase = false, Production Mode = true
2286 1737967045637 GEN4_TO_CONTROLLER_LOG:GEN4_PROGRAM_INT_LOG_ATSAME54P20A TransferInfo: Start = 804000, End = 8041ff, Buffer Length = 512, Type = Cfg, Mask = 00000002
2286 1737967045637 GEN4_TO_CONTROLLER_LOG:GEN4_PROGRAM_INT_LOG_ATSAME54P20A Payload End
2286 1737967045637 XXXX 1737967045637, Thread 2286: XXXX 1737967045637, Entering Thread 2286: Commands::runScriptWithUpload, script name = ReadConfigmem  
2286 1737967045637 XXXX 1737967045637, Thread 2286: XXXX 1737967045637, Entering Thread 2286: ToolCommUsb::readTransfer, sideData is 0x24 bytes long, transferDataLength is 0x200 bytes long  
2286 1737967045648 XXXX 1737967045648, Thread 2286: XXXX 1737967045648, Exiting Thread 2286: ToolCommUsb::readTransfer,  cr.status = 0x0  
2286 1737967045648 XXXX 1737967045648, Thread 2286: XXXX 1737967045648, Exiting Thread 2286: Commands::runScriptWithUpload  
2286 1737967045648 GEN4_TO_CONTROLLER_LOG:GEN4_PROGRAM_INT_LOG_ATSAME54P20A Post:SendOperation
2286 1737967045648 GEN4_TO_CONTROLLER_LOG:GEN4_PROGRAM_INT_LOG_ATSAME54P20A Return Value
2286 1737967045648 GEN4_TO_CONTROLLER_LOG:GEN4_PROGRAM_INT_LOG_ATSAME54P20A None
2286 1737967045648 GEN4_TO_CONTROLLER_LOG:GEN4_PROGRAM_INT_LOG_ATSAME54P20A Return End

2286 1737967045648 GEN4_TO_CONTROLLER_LOG:GEN4_PROGRAM_INT_LOG_ATSAME54P20A Pre:SendOperation
2286 1737967045648 GEN4_TO_CONTROLLER_LOG:GEN4_PROGRAM_INT_LOG_ATSAME54P20A Payload
2286 1737967045648 GEN4_TO_CONTROLLER_LOG:GEN4_PROGRAM_INT_LOG_ATSAME54P20A OperationInfo: Values:
2286 1737967045648 GEN4_TO_CONTROLLER_LOG:GEN4_PROGRAM_INT_LOG_ATSAME54P20A OperationInfo: Type = write, Mask = 00000000, Erase = false, Production Mode = true
2286 1737967045648 GEN4_TO_CONTROLLER_LOG:GEN4_PROGRAM_INT_LOG_ATSAME54P20A TransferInfo: Start = 0, End = 61fff, Buffer Length = 401408, Type = Pgm, Mask = 00000000
2286 1737967045648 GEN4_TO_CONTROLLER_LOG:GEN4_PROGRAM_INT_LOG_ATSAME54P20A TransferInfo: Start = 804000, End = 8041ff, Buffer Length = 512, Type = Cfg, Mask = 00000002
2286 1737967045648 GEN4_TO_CONTROLLER_LOG:GEN4_PROGRAM_INT_LOG_ATSAME54P20A TransferInfo: Start = 20002000, End = 20003fff, Buffer Length = 8192, Type = FileRegs, Mask = 00000000
2286 1737967045648 GEN4_TO_CONTROLLER_LOG:GEN4_PROGRAM_INT_LOG_ATSAME54P20A Payload End
2286 1737967045648 XXXX 1737967045648, Thread 2286: XXXX 1737967045648, Entering Thread 2286: Commands::runScriptWithDownload, script name = WriteProgmem  
2286 1737967050608 XXXX 1737967050608, Thread 2286: XXXX 1737967050608, Exiting Thread 2286: Commands::runScriptWithDownload(WriteProgmem)  
2286 1737967050608 XXXX 1737967050608, Thread 2286: XXXX 1737967050608, Entering Thread 2286: Commands::runScriptWithUpload, script name = ReadProgmem  
2286 1737967050608 XXXX 1737967050608, Thread 2286: XXXX 1737967050608, Entering Thread 2286: ToolCommUsb::readTransfer, sideData is 0x24 bytes long, transferDataLength is 0x62000 bytes long  
2286 1737967053969 XXXX 1737967053969, Thread 2286: XXXX 1737967053969, Exiting Thread 2286: ToolCommUsb::readTransfer,  cr.status = 0x0  
2286 1737967053969 XXXX 1737967053969, Thread 2286: XXXX 1737967053969, Exiting Thread 2286: Commands::runScriptWithUpload  
2286 1737967053970 XXXX 1737967053970, Thread 2286: XXXX 1737967053970, Entering Thread 2286: Commands::runScriptBasic, script name = EraseConfigmem, timeOut = -1 ms  
2286 1737967053980 XXXX 1737967053980, Thread 2286: XXXX 1737967053980, Exiting Thread 2286: Commands::runScriptBasic  
2286 1737967053980 XXXX 1737967053980, Thread 2286: XXXX 1737967053980, Entering Thread 2286: Commands::runScriptWithDownload, script name = WriteConfigmem  
2286 1737967053994 XXXX 1737967053994, Thread 2286: XXXX 1737967053994, Exiting Thread 2286: Commands::runScriptWithDownload(WriteConfigmem)  
2286 1737967053994 XXXX 1737967053994, Thread 2286: XXXX 1737967053994, Entering Thread 2286: Commands::runScriptWithUpload, script name = ReadConfigmem  
2286 1737967053994 XXXX 1737967053994, Thread 2286: XXXX 1737967053994, Entering Thread 2286: ToolCommUsb::readTransfer, sideData is 0x24 bytes long, transferDataLength is 0x200 bytes long  
2286 1737967054000 XXXX 1737967054000, Thread 2286: XXXX 1737967054000, Exiting Thread 2286: ToolCommUsb::readTransfer,  cr.status = 0x0  
2286 1737967054000 XXXX 1737967054000, Thread 2286: XXXX 1737967054000, Exiting Thread 2286: Commands::runScriptWithUpload  
2286 1737967054000 XXXX 1737967054000, Thread 2286: XXXX 1737967054000, Entering Thread 2286: Commands::runScriptWithDownload, script name = WriteEmu  
2286 1737967054072 XXXX 1737967054072, Thread 2286: XXXX 1737967054072, Exiting Thread 2286: Commands::runScriptWithDownload(WriteEmu)  
2286 1737967054072 XXXX 1737967054072, Thread 2286: XXXX 1737967054072, Entering Thread 2286: Commands::runScriptWithUpload, script name = ReadEmu  
2286 1737967054072 XXXX 1737967054072, Thread 2286: XXXX 1737967054072, Entering Thread 2286: ToolCommUsb::readTransfer, sideData is 0x24 bytes long, transferDataLength is 0x2000 bytes long  
2286 1737967054141 XXXX 1737967054141, Thread 2286: XXXX 1737967054141, Exiting Thread 2286: ToolCommUsb::readTransfer,  cr.status = 0x0  
2286 1737967054141 XXXX 1737967054141, Thread 2286: XXXX 1737967054141, Exiting Thread 2286: Commands::runScriptWithUpload  
2286 1737967054141 GEN4_TO_CONTROLLER_LOG:GEN4_PROGRAM_INT_LOG_ATSAME54P20A Post:SendOperation
2286 1737967054141 GEN4_TO_CONTROLLER_LOG:GEN4_PROGRAM_INT_LOG_ATSAME54P20A Return Value
2286 1737967054141 GEN4_TO_CONTROLLER_LOG:GEN4_PROGRAM_INT_LOG_ATSAME54P20A None
2286 1737967054141 GEN4_TO_CONTROLLER_LOG:GEN4_PROGRAM_INT_LOG_ATSAME54P20A Return End

2286 1737967054141 GEN4_TO_CONTROLLER_LOG:GEN4_PROGRAM_INT_LOG_ATSAME54P20A Pre:endOfOperations
2286 1737967054141 GEN4_TO_CONTROLLER_LOG:GEN4_PROGRAM_INT_LOG_ATSAME54P20A Payload
2286 1737967054141 GEN4_TO_CONTROLLER_LOG:GEN4_PROGRAM_INT_LOG_ATSAME54P20A null
2286 1737967054141 GEN4_TO_CONTROLLER_LOG:GEN4_PROGRAM_INT_LOG_ATSAME54P20A Payload End
2286 1737967054141 GEN4_TO_CONTROLLER_LOG:GEN4_PROGRAM_INT_LOG_ATSAME54P20A Post:endOfOperations
2286 1737967054141 GEN4_TO_CONTROLLER_LOG:GEN4_PROGRAM_INT_LOG_ATSAME54P20A Return Value
2286 1737967054141 GEN4_TO_CONTROLLER_LOG:GEN4_PROGRAM_INT_LOG_ATSAME54P20A None
2286 1737967054141 GEN4_TO_CONTROLLER_LOG:GEN4_PROGRAM_INT_LOG_ATSAME54P20A Return End

2286 1737967054151 GEN4_TO_CONTROLLER_LOG:GEN4_PROGRAM_INT_LOG_ATSAME54P20A Pre:SendOperation
2286 1737967054151 GEN4_TO_CONTROLLER_LOG:GEN4_PROGRAM_INT_LOG_ATSAME54P20A Payload
2286 1737967054151 GEN4_TO_CONTROLLER_LOG:GEN4_PROGRAM_INT_LOG_ATSAME54P20A OperationInfo: Values:
2286 1737967054151 GEN4_TO_CONTROLLER_LOG:GEN4_PROGRAM_INT_LOG_ATSAME54P20A OperationInfo: Type = releasefromreset, Mask = 00000000, Erase = false, Production Mode = true
2286 1737967054151 GEN4_TO_CONTROLLER_LOG:GEN4_PROGRAM_INT_LOG_ATSAME54P20A Payload End
2286 1737967054152 XXXX 1737967054152, Thread 2286: XXXX 1737967054152, Entering Thread 2286: Commands::runScriptBasic, script name = UnInitSWD, timeOut = -1 ms  
2286 1737967054156 XXXX 1737967054156, Thread 2286: XXXX 1737967054156, Exiting Thread 2286: Commands::runScriptBasic  
2286 1737967054156 XXXX 1737967054156, Thread 2286: XXXX 1737967054156, Entering Thread 2286: Commands::runScriptBasic with script contents. contents[0] = 0xb1, ...  
2286 1737967054159 XXXX 1737967054159, Thread 2286: XXXX 1737967054159, Exiting Thread 2286: Commands::runScriptBasic  
2286 1737967054159 XXXX 1737967054159, Thread 2286: XXXX 1737967054159, Entering Thread 2286: Commands::runScriptBasic with script contents. contents[0] = 0xef, ...  
2286 1737967054160 XXXX 1737967054160, Thread 2286: XXXX 1737967054160, Exiting Thread 2286: Commands::runScriptBasic  
2286 1737967054160 GEN4_TO_CONTROLLER_LOG:GEN4_PROGRAM_INT_LOG_ATSAME54P20A Post:SendOperation
2286 1737967054160 GEN4_TO_CONTROLLER_LOG:GEN4_PROGRAM_INT_LOG_ATSAME54P20A Return Value
2286 1737967054160 GEN4_TO_CONTROLLER_LOG:GEN4_PROGRAM_INT_LOG_ATSAME54P20A None
2286 1737967054160 GEN4_TO_CONTROLLER_LOG:GEN4_PROGRAM_INT_LOG_ATSAME54P20A Return End
2286 1737967054161 GEN4_CONNECT_DIAGNOSTICS:MPLABCommTool is null

2286 1737967054161 GEN4_TO_CONTROLLER_LOG:GEN4_CONNECT_INT_LOG_ATSAME54P20A Pre:GetFirmwareInfo
2286 1737967054161 GEN4_TO_CONTROLLER_LOG:GEN4_CONNECT_INT_LOG_ATSAME54P20A Payload
2286 1737967054161 GEN4_TO_CONTROLLER_LOG:GEN4_CONNECT_INT_LOG_ATSAME54P20A null
2286 1737967054161 GEN4_TO_CONTROLLER_LOG:GEN4_CONNECT_INT_LOG_ATSAME54P20A Payload End
2286 1737967054169 GEN4_TO_CONTROLLER_LOG:GEN4_CONNECT_INT_LOG_ATSAME54P20A Post:GetFirmwareInfo
2286 1737967054169 GEN4_TO_CONTROLLER_LOG:GEN4_CONNECT_INT_LOG_ATSAME54P20A Return Value
2286 1737967054169 GEN4_TO_CONTROLLER_LOG:GEN4_CONNECT_INT_LOG_ATSAME54P20A FirmwareInfo: Values:
2286 1737967054169 GEN4_TO_CONTROLLER_LOG:GEN4_CONNECT_INT_LOG_ATSAME54P20A FirmwareInfo: boot = false, bootVer = 01.01.41, apVer = 00.09.08, fpgaVer = ff.ff.ff, scriptVer = 00.08.73, macAddress = 0495683578451535048485252484953, devID = a1020e01, devID1 = 1, devSN0 = ffffffff, devSN1 = ffffffff, serialNumber = 020012202RYN000072, appCommitID = null, scriptCommitID = df19a696ae, PCB_ID = 80000000
2286 1737967054169 GEN4_TO_CONTROLLER_LOG:GEN4_CONNECT_INT_LOG_ATSAME54P20A Return End

2286 1737967054169 GEN4_TO_CONTROLLER_LOG:GEN4_CONNECT_INT_LOG_ATSAME54P20A Pre:SetPowerInfo
2286 1737967054169 GEN4_TO_CONTROLLER_LOG:GEN4_CONNECT_INT_LOG_ATSAME54P20A Payload
2286 1737967054169 GEN4_TO_CONTROLLER_LOG:GEN4_CONNECT_INT_LOG_ATSAME54P20A PowerInfo: Values:
2286 1737967054169 GEN4_TO_CONTROLLER_LOG:GEN4_CONNECT_INT_LOG_ATSAME54P20A PowerInfo: shotDownSystem = false, isToolPower = false, voltage = 3.300000, useVppFirst = false, useLowVoltageProgramming = true, useMaintainActivePower = false
2286 1737967054169 GEN4_TO_CONTROLLER_LOG:GEN4_CONNECT_INT_LOG_ATSAME54P20A Payload End
2286 1737967054170 XXXX 1737967054170, Thread 2286: XXXX 1737967054170, Entering Thread 2286: Commands::runScriptBasic with script contents. contents[0] = 0x39, ...  
2286 1737967054171 XXXX 1737967054171, Thread 2286: XXXX 1737967054171, Exiting Thread 2286: Commands::runScriptBasic  
2286 1737967054171 XXXX 1737967054171, Thread 2286: XXXX 1737967054171, Entering Thread 2286: Commands::runScriptBasic with script contents. contents[0] = 0x46, ...  
2286 1737967054173 XXXX 1737967054173, Thread 2286: XXXX 1737967054173, Exiting Thread 2286: Commands::runScriptBasic  
2286 1737967054174 XXXX 1737967054174, Thread 2286: XXXX 1737967054174, Entering Thread 2286: Commands::runScriptBasic with script contents. contents[0] = 0x44, ...  
2286 1737967054175 XXXX 1737967054175, Thread 2286: XXXX 1737967054175, Exiting Thread 2286: Commands::runScriptBasic  
2286 1737967054175 XXXX 1737967054175, Thread 2286: XXXX 1737967054175, Entering Thread 2286: Commands::runScriptBasic with script contents. contents[0] = 0xef, ...  
2286 1737967054176 XXXX 1737967054176, Thread 2286: XXXX 1737967054176, Exiting Thread 2286: Commands::runScriptBasic  
2286 1737967054176 XXXX 1737967054176, Thread 2286: XXXX 1737967054176, Entering Thread 2286: Commands::runScriptBasic with script contents. contents[0] = 0x40, ...  
2286 1737967054177 XXXX 1737967054177, Thread 2286: XXXX 1737967054177, Exiting Thread 2286: Commands::runScriptBasic  
2286 1737967054177 XXXX 1737967054177, Thread 2286: XXXX 1737967054177, Entering Thread 2286: Commands::runScriptBasic with script contents. contents[0] = 0x47, ...  
2286 1737967054178 XXXX 1737967054178, Thread 2286: XXXX 1737967054178, Exiting Thread 2286: Commands::runScriptBasic  
2286 1737967054178 GEN4_TO_CONTROLLER_LOG:GEN4_CONNECT_INT_LOG_ATSAME54P20A Post:SetPowerInfo
2286 1737967054178 GEN4_TO_CONTROLLER_LOG:GEN4_CONNECT_INT_LOG_ATSAME54P20A Return Value
2286 1737967054178 GEN4_TO_CONTROLLER_LOG:GEN4_CONNECT_INT_LOG_ATSAME54P20A none
2286 1737967054178 GEN4_TO_CONTROLLER_LOG:GEN4_CONNECT_INT_LOG_ATSAME54P20A Return End
2286 1737967054178 GEN4_CONNECT_DIAGNOSTICS:Removing plug and play observer com.microchip.mplab.mdbcore.RI4Tool.RI4ToolBase$RI4PlugNPlayObserver@34708d50
2286 1737967054178 GEN4_CONNECT_DIAGNOSTICS:Begin PlugNPlayObservers list dump:
2286 1737967054178 GEN4_CONNECT_DIAGNOSTICS:End PlugNPlayObservers list dump:
2286 1737967054229 GEN4_CONNECT_DIAGNOSTICS:Calling RIDbgToolCom.Disconnect
2286 1737967054229 GEN4_CONNECT_DIAGNOSTICS:Calling MPLABCommTool.Detach to remove tool from plug and play list
2286 1737967054229 GEN4_CONNECT_DIAGNOSTICS:Calling RIDbgToolCom.DisconnectFromMPlabComm
2286 1737967054229 GEN4_CONNECT_DIAGNOSTICS:Calling MPLABCommTool.Disconnect
2441 1737967271407 GEN4_CONNECT_DIAGNOSTICS:MPLABCommTool is NOT null
2441 1737967271407 GEN4_CONNECT_DIAGNOSTICS:AttachedToolPID = 810b, AttachedToolVID = 4d8
2441 1737967271407 GEN4_CONNECT_DIAGNOSTICS:transport type = USB
2441 1737967271407 GEN4_CONNECT_DIAGNOSTICS:AttachedToolPID = 810b, AttachedToolVID = 4d8
2441 1737967271447 com.microchip.mplab.mdbcore.RealICETool.RIDbgToolCom
2441 1737967271447 GEN4_CONNECT_DIAGNOSTICS:Before MPLABCommTool.Connect()
2441 1737967271447 GEN4_CONNECT_DIAGNOSTICS:After MPLABCommTool.Connect()
2441 1737967271447 GEN4_CONNECT_DIAGNOSTICS:MPLABCommTool.Connect() returned MPLABCOMM_NO_ERROR
2441 1737967271447 GEN4_CONNECT_DIAGNOSTICS:Attaching to MPLABCommTool plugnplay
2441 1737967271447 GEN4_CONNECT_DIAGNOSTICS:Adding new plug and play observer com.microchip.mplab.mdbcore.RI4Tool.RI4ToolBase$RI4PlugNPlayObserver@67916f58
2441 1737967271447 GEN4_CONNECT_DIAGNOSTICS:Begin PlugNPlayObservers list dump:
2441 1737967271447 GEN4_CONNECT_DIAGNOSTICS:com.microchip.mplab.mdbcore.RI4Tool.RI4ToolBase$RI4PlugNPlayObserver@67916f58
2441 1737967271447 GEN4_CONNECT_DIAGNOSTICS:End PlugNPlayObservers list dump:
2441 1737967271448 GEN4_CONNECT_DIAGNOSTICS:Registering for alternate PNP notifications. CommPnPCriteria.cPIDList = [810A, 8109, 2184], CommPnPCriteria.cSerialNumber = 020012202ryn000072

2441 1737967271574 GEN4_TO_CONTROLLER_LOG:GEN4_INIT_INT_LOG_ATSAME54P20A Pre:init
2441 1737967271574 GEN4_TO_CONTROLLER_LOG:GEN4_INIT_INT_LOG_ATSAME54P20A Payload
2441 1737967271574 GEN4_TO_CONTROLLER_LOG:GEN4_INIT_INT_LOG_ATSAME54P20A DeviceInfo: Values:
2441 1737967271574 GEN4_TO_CONTROLLER_LOG:GEN4_INIT_INT_LOG_ATSAME54P20A DeviceInfo: pcAddress = 7fffffffffffffff, Vpp = 3.30, useRowEraseIfVoltageIsLow = false, voltageBelowWhichUseRowErase = 0.00, deviceName = ATSAME54P20A, programmerType = NVMCTRL_U2409
2441 1737967271574 GEN4_TO_CONTROLLER_LOG:GEN4_INIT_INT_LOG_ATSAME54P20A DeviceInfo: MemInfo values:
2441 1737967271574 GEN4_TO_CONTROLLER_LOG:GEN4_INIT_INT_LOG_ATSAME54P20A DeviceInfo: mask = ffffffff, exists = true, startAddr = 00000000, endAddr = 47001fff, rowSize = 2000, rowEraseSize = 2000, addrInc = 0004, widthProgram = 0004
2441 1737967271574 GEN4_TO_CONTROLLER_LOG:GEN4_INIT_INT_LOG_ATSAME54P20A DeviceInfo: mask = ffffffff, exists = true, startAddr = 00804000, endAddr = 0080400b, rowSize = 0001, rowEraseSize = 0000, addrInc = 0004, widthProgram = 0004
2441 1737967271574 GEN4_TO_CONTROLLER_LOG:GEN4_INIT_INT_LOG_ATSAME54P20A DeviceInfo: mask = 0000, exists = false, startAddr = 00000000, endAddr = 00000000, rowSize = 0000, rowEraseSize = 0000, addrInc = 0000, widthProgram = 0000
2441 1737967271574 GEN4_TO_CONTROLLER_LOG:GEN4_INIT_INT_LOG_ATSAME54P20A DeviceInfo: mask = 0000, exists = false, startAddr = 00000000, endAddr = 00000000, rowSize = 0000, rowEraseSize = 0000, addrInc = 0000, widthProgram = 0000
2441 1737967271574 GEN4_TO_CONTROLLER_LOG:GEN4_INIT_INT_LOG_ATSAME54P20A DeviceInfo: mask = ffffffff, exists = true, startAddr = 0080400c, endAddr = 008041ff, rowSize = 0200, rowEraseSize = 0000, addrInc = 0004, widthProgram = 0004
2441 1737967271574 GEN4_TO_CONTROLLER_LOG:GEN4_INIT_INT_LOG_ATSAME54P20A DeviceInfo: mask = 0000, exists = false, startAddr = 00000000, endAddr = 00000000, rowSize = 0000, rowEraseSize = 2000, addrInc = 0000, widthProgram = 0000
2441 1737967271574 GEN4_TO_CONTROLLER_LOG:GEN4_INIT_INT_LOG_ATSAME54P20A DeviceInfo: mask = 0000, exists = false, startAddr = 00000000, endAddr = 00000000, rowSize = 0000, rowEraseSize = 0000, addrInc = 0004, widthProgram = 0004
2441 1737967271574 GEN4_TO_CONTROLLER_LOG:GEN4_INIT_INT_LOG_ATSAME54P20A DeviceInfo: mask = ffffffff, exists = true, startAddr = 03000000, endAddr = e0041fff, rowSize = 0000, rowEraseSize = 0000, addrInc = 0004, widthProgram = 0004
2441 1737967271574 GEN4_TO_CONTROLLER_LOG:GEN4_INIT_INT_LOG_ATSAME54P20A DeviceInfo: mask = 0000, exists = false, startAddr = 00000000, endAddr = 00000000, rowSize = 0000, rowEraseSize = 0000, addrInc = 0000, widthProgram = 0000
2441 1737967271574 GEN4_TO_CONTROLLER_LOG:GEN4_INIT_INT_LOG_ATSAME54P20A DeviceInfo: mask = 0000, exists = false, startAddr = 00000000, endAddr = 00000000, rowSize = 0000, rowEraseSize = 0000, addrInc = 0000, widthProgram = 0000
2441 1737967271574 GEN4_TO_CONTROLLER_LOG:GEN4_INIT_INT_LOG_ATSAME54P20A DeviceInfo: mask = 0000, exists = false, startAddr = 00000000, endAddr = 00000000, rowSize = 0000, rowEraseSize = 0000, addrInc = 0004, widthProgram = 0004
2441 1737967271574 GEN4_TO_CONTROLLER_LOG:GEN4_INIT_INT_LOG_ATSAME54P20A DeviceInfo: mask = 0000, exists = false, startAddr = 00000000, endAddr = 00000000, rowSize = 0000, rowEraseSize = 0000, addrInc = 0004, widthProgram = 0004
2441 1737967271574 GEN4_TO_CONTROLLER_LOG:GEN4_INIT_INT_LOG_ATSAME54P20A DeviceInfo: mask = 0000, exists = false, startAddr = 00000000, endAddr = 00000000, rowSize = 0000, rowEraseSize = 0000, addrInc = 0000, widthProgram = 0000
2441 1737967271574 GEN4_TO_CONTROLLER_LOG:GEN4_INIT_INT_LOG_ATSAME54P20A DeviceInfo: mask = 0000, exists = false, startAddr = 00000000, endAddr = 00000000, rowSize = 0000, rowEraseSize = 0000, addrInc = 0000, widthProgram = 0000
2441 1737967271574 GEN4_TO_CONTROLLER_LOG:GEN4_INIT_INT_LOG_ATSAME54P20A DeviceInfo: mask = 0000, exists = false, startAddr = 00000000, endAddr = 00000000, rowSize = 0000, rowEraseSize = 0000, addrInc = 0000, widthProgram = 0000
2441 1737967271574 GEN4_TO_CONTROLLER_LOG:GEN4_INIT_INT_LOG_ATSAME54P20A DeviceInfo: mask = 0000, exists = false, startAddr = 00000000, endAddr = 00000000, rowSize = 0000, rowEraseSize = 0000, addrInc = 0000, widthProgram = 0000
2441 1737967271574 GEN4_TO_CONTROLLER_LOG:GEN4_INIT_INT_LOG_ATSAME54P20A DeviceInfo: mask = 7fffffff, exists = true, startAddr = 41002018, endAddr = 4100201b, rowSize = 0001, rowEraseSize = 0000, addrInc = 0001, widthProgram = 0001
2441 1737967271574 GEN4_TO_CONTROLLER_LOG:GEN4_INIT_INT_LOG_ATSAME54P20A DeviceInfo: mask = 0000, exists = false, startAddr = 00000000, endAddr = 00000000, rowSize = 0000, rowEraseSize = 0000, addrInc = 0000, widthProgram = 0000
2441 1737967271574 GEN4_TO_CONTROLLER_LOG:GEN4_INIT_INT_LOG_ATSAME54P20A DeviceInfo: mask = 0000, exists = false, startAddr = 00000000, endAddr = 00000000, rowSize = 0000, rowEraseSize = 0000, addrInc = 0000, widthProgram = 0000
2441 1737967271574 GEN4_TO_CONTROLLER_LOG:GEN4_INIT_INT_LOG_ATSAME54P20A DeviceInfo: mask = 0000, exists = false, startAddr = 00000000, endAddr = 00000000, rowSize = 0000, rowEraseSize = 0000, addrInc = 0000, widthProgram = 0000
2441 1737967271574 GEN4_TO_CONTROLLER_LOG:GEN4_INIT_INT_LOG_ATSAME54P20A DeviceInfo: mask = 0000, exists = false, startAddr = 00000000, endAddr = 00000000, rowSize = 0000, rowEraseSize = 0000, addrInc = 0000, widthProgram = 0000
2441 1737967271574 GEN4_TO_CONTROLLER_LOG:GEN4_INIT_INT_LOG_ATSAME54P20A DeviceInfo: mask = 0000, exists = false, startAddr = 00000000, endAddr = 00000000, rowSize = 0000, rowEraseSize = 0000, addrInc = 0000, widthProgram = 0000
2441 1737967271574 GEN4_TO_CONTROLLER_LOG:GEN4_INIT_INT_LOG_ATSAME54P20A DeviceInfo: mask = 0000, exists = false, startAddr = 00000000, endAddr = 00000000, rowSize = 0000, rowEraseSize = 0000, addrInc = 0000, widthProgram = 0000
2441 1737967271574 GEN4_TO_CONTROLLER_LOG:GEN4_INIT_INT_LOG_ATSAME54P20A CfgRequiredBitsMask Values:
2441 1737967271574 GEN4_TO_CONTROLLER_LOG:GEN4_INIT_INT_LOG_ATSAME54P20A Address = 00804000, Mask = 3c007fff
2441 1737967271574 GEN4_TO_CONTROLLER_LOG:GEN4_INIT_INT_LOG_ATSAME54P20A Address = 00804004, Mask = 7fff00ff
2441 1737967271574 GEN4_TO_CONTROLLER_LOG:GEN4_INIT_INT_LOG_ATSAME54P20A Address = 00804008, Mask = ffffffff
2441 1737967271574 GEN4_TO_CONTROLLER_LOG:GEN4_INIT_INT_LOG_ATSAME54P20A BasicInfo: Values:
2441 1737967271575 GEN4_TO_CONTROLLER_LOG:GEN4_INIT_INT_LOG_ATSAME54P20A BasicInfo: InputStream = com.microchip.mplab.libs.toolpacksupport.EquatableFileInputStream@2014eefd, ToolFlavor = PICKit4
2441 1737967271575 GEN4_TO_CONTROLLER_LOG:GEN4_INIT_INT_LOG_ATSAME54P20A Payload End
2441 1737967271575 GEN4_TO_CONTROLLER_LOG:GEN4_INIT_INT_LOG_ATSAME54P20A Post:init
2441 1737967271575 GEN4_TO_CONTROLLER_LOG:GEN4_INIT_INT_LOG_ATSAME54P20A Return Value
2441 1737967271575 GEN4_TO_CONTROLLER_LOG:GEN4_INIT_INT_LOG_ATSAME54P20A none
2441 1737967271575 GEN4_TO_CONTROLLER_LOG:GEN4_INIT_INT_LOG_ATSAME54P20A Return End

2441 1737967271575 GEN4_TO_CONTROLLER_LOG:GEN4_INIT_INT_LOG_ATSAME54P20A Pre:GetInterfaceProvider
2441 1737967271575 GEN4_TO_CONTROLLER_LOG:GEN4_INIT_INT_LOG_ATSAME54P20A Payload
2441 1737967271575 GEN4_TO_CONTROLLER_LOG:GEN4_INIT_INT_LOG_ATSAME54P20A RI4DebugInterface
2441 1737967271575 GEN4_TO_CONTROLLER_LOG:GEN4_INIT_INT_LOG_ATSAME54P20A Payload End
2441 1737967271575 GEN4_TO_CONTROLLER_LOG:GEN4_INIT_INT_LOG_ATSAME54P20A Post:GetInterfaceProvider
2441 1737967271575 GEN4_TO_CONTROLLER_LOG:GEN4_INIT_INT_LOG_ATSAME54P20A Return Value
2441 1737967271575 GEN4_TO_CONTROLLER_LOG:GEN4_INIT_INT_LOG_ATSAME54P20A com.microchip.mplab.libs.RI4ToolsController.implementations.RI4DebugInterfaceImpl@782c3696
2441 1737967271575 GEN4_TO_CONTROLLER_LOG:GEN4_INIT_INT_LOG_ATSAME54P20A Return End

2441 1737967271575 GEN4_TO_CONTROLLER_LOG:GEN4_INIT_INT_LOG_ATSAME54P20A Pre:GetInterfaceProvider
2441 1737967271575 GEN4_TO_CONTROLLER_LOG:GEN4_INIT_INT_LOG_ATSAME54P20A Payload
2441 1737967271575 GEN4_TO_CONTROLLER_LOG:GEN4_INIT_INT_LOG_ATSAME54P20A RI4ProgramInterface
2441 1737967271575 GEN4_TO_CONTROLLER_LOG:GEN4_INIT_INT_LOG_ATSAME54P20A Payload End
2441 1737967271575 GEN4_TO_CONTROLLER_LOG:GEN4_INIT_INT_LOG_ATSAME54P20A Post:GetInterfaceProvider
2441 1737967271575 GEN4_TO_CONTROLLER_LOG:GEN4_INIT_INT_LOG_ATSAME54P20A Return Value
2441 1737967271575 GEN4_TO_CONTROLLER_LOG:GEN4_INIT_INT_LOG_ATSAME54P20A com.microchip.mplab.libs.RI4ToolsController.implementations.RI4ProgramInterfaceImpl@f58b164
2441 1737967271575 GEN4_TO_CONTROLLER_LOG:GEN4_INIT_INT_LOG_ATSAME54P20A Return End

2441 1737967271575 GEN4_TO_CONTROLLER_LOG:GEN4_INIT_INT_LOG_ATSAME54P20A Pre:GetInterfaceProvider
2441 1737967271575 GEN4_TO_CONTROLLER_LOG:GEN4_INIT_INT_LOG_ATSAME54P20A Payload
2441 1737967271575 GEN4_TO_CONTROLLER_LOG:GEN4_INIT_INT_LOG_ATSAME54P20A RI4ConnectInterface
2441 1737967271575 GEN4_TO_CONTROLLER_LOG:GEN4_INIT_INT_LOG_ATSAME54P20A Payload End
2441 1737967271575 GEN4_TO_CONTROLLER_LOG:GEN4_INIT_INT_LOG_ATSAME54P20A Post:GetInterfaceProvider
2441 1737967271575 GEN4_TO_CONTROLLER_LOG:GEN4_INIT_INT_LOG_ATSAME54P20A Return Value
2441 1737967271575 GEN4_TO_CONTROLLER_LOG:GEN4_INIT_INT_LOG_ATSAME54P20A com.microchip.mplab.libs.PK4ToolsController.PK4ConnectInterfaceImpl@63dff478
2441 1737967271575 GEN4_TO_CONTROLLER_LOG:GEN4_INIT_INT_LOG_ATSAME54P20A Return End
2441 1737967271576 GEN4_CONNECT_DIAGNOSTICS:acceptablePIDs = [810a, 8109, 810b]
2441 1737967271577 GEN4_CONNECT_DIAGNOSTICS:otherPIDs = [2184]
2441 1737967271577 GEN4_CONNECT_DIAGNOSTICS:Setting selected tool type to pk4
2441 1737967271577 GEN4_CONNECT_DIAGNOSTICS:otherPIDs = [2184]
2441 1737967271577 GEN4_CONNECT_DIAGNOSTICS:acceptablePIDs = [810a, 8109, 810b]

2441 1737967271577 GEN4_TO_CONTROLLER_LOG:GEN4_INIT_INT_LOG_ATSAME54P20A Pre:GetInterfaceProvider
2441 1737967271577 GEN4_TO_CONTROLLER_LOG:GEN4_INIT_INT_LOG_ATSAME54P20A Payload
2441 1737967271577 GEN4_TO_CONTROLLER_LOG:GEN4_INIT_INT_LOG_ATSAME54P20A RI4ControllerDiagnosticsInterface
2441 1737967271577 GEN4_TO_CONTROLLER_LOG:GEN4_INIT_INT_LOG_ATSAME54P20A Payload End
2441 1737967271577 GEN4_TO_CONTROLLER_LOG:GEN4_INIT_INT_LOG_ATSAME54P20A Post:GetInterfaceProvider
2441 1737967271577 GEN4_TO_CONTROLLER_LOG:GEN4_INIT_INT_LOG_ATSAME54P20A Return Value
2441 1737967271577 GEN4_TO_CONTROLLER_LOG:GEN4_INIT_INT_LOG_ATSAME54P20A com.microchip.mplab.libs.RI4ToolsController.implementations.RI4ControllerDiagnosticsInterfaceImpl@269b0113
2441 1737967271577 GEN4_TO_CONTROLLER_LOG:GEN4_INIT_INT_LOG_ATSAME54P20A Return End

2441 1737967271577 GEN4_TO_CONTROLLER_LOG:GEN4_INIT_INT_LOG_ATSAME54P20A Pre:GetInterfaceProvider
2441 1737967271577 GEN4_TO_CONTROLLER_LOG:GEN4_INIT_INT_LOG_ATSAME54P20A Payload
2441 1737967271577 GEN4_TO_CONTROLLER_LOG:GEN4_INIT_INT_LOG_ATSAME54P20A ProgrammerToGo
2441 1737967271577 GEN4_TO_CONTROLLER_LOG:GEN4_INIT_INT_LOG_ATSAME54P20A Payload End
2441 1737967271577 GEN4_TO_CONTROLLER_LOG:GEN4_INIT_INT_LOG_ATSAME54P20A Post:GetInterfaceProvider
2441 1737967271577 GEN4_TO_CONTROLLER_LOG:GEN4_INIT_INT_LOG_ATSAME54P20A Return Value
2441 1737967271577 GEN4_TO_CONTROLLER_LOG:GEN4_INIT_INT_LOG_ATSAME54P20A com.microchip.mplab.libs.RI4ToolsController.implementations.ProgrammerToGoImpl@3f9a0bd0
2441 1737967271577 GEN4_TO_CONTROLLER_LOG:GEN4_INIT_INT_LOG_ATSAME54P20A Return End

2441 1737967271577 GEN4_TO_CONTROLLER_LOG:GEN4_INIT_INT_LOG_ATSAME54P20A Pre:GetInterfaceProvider
2441 1737967271577 GEN4_TO_CONTROLLER_LOG:GEN4_INIT_INT_LOG_ATSAME54P20A Payload
2441 1737967271577 GEN4_TO_CONTROLLER_LOG:GEN4_INIT_INT_LOG_ATSAME54P20A Status
2441 1737967271577 GEN4_TO_CONTROLLER_LOG:GEN4_INIT_INT_LOG_ATSAME54P20A Payload End
2441 1737967271577 GEN4_TO_CONTROLLER_LOG:GEN4_INIT_INT_LOG_ATSAME54P20A Post:GetInterfaceProvider
2441 1737967271577 GEN4_TO_CONTROLLER_LOG:GEN4_INIT_INT_LOG_ATSAME54P20A Return Value
2441 1737967271577 GEN4_TO_CONTROLLER_LOG:GEN4_INIT_INT_LOG_ATSAME54P20A null
2441 1737967271577 GEN4_TO_CONTROLLER_LOG:GEN4_INIT_INT_LOG_ATSAME54P20A Return End
2441 1737967271720 GEN4_CONNECT_DIAGNOSTICS:ENTERING: com.microchip.mplab.mdbcore.RI4Tool.ConnectionHandler.CheckForFWUpdates()
2441 1737967271720 GEN4_CONNECT_DIAGNOSTICS:Created FirmwareUpdateHandler com.microchip.mplab.mdbcore.pk4hybrid.pk4hybridFirmwareUpdateHandler@75834ed6
2441 1737967271721 GEN4_CONNECT_DIAGNOSTICS:ENTERING: com.microchip.mplab.mdbcore.pk4hybrid.pk4hybridFirmwareUpdateHandler.UpdateFirmware(FirmwareInfo, UpdateMessage)
2441 1737967271721 GEN4_CONNECT_DIAGNOSTICS:areWeInBoot returned false
2441 1737967271721 GEN4_CONNECT_DIAGNOSTICS:inBoot = false
2441 1737967271721 GEN4_CONNECT_DIAGNOSTICS:uMode = checkingVersions
2441 1737967271721 GEN4_CONNECT_DIAGNOSTICS:selectedTool = pk4
2441 1737967271721 GEN4_CONNECT_DIAGNOSTICS:current toolType = pk4
2441 1737967271721 GEN4_CONNECT_DIAGNOSTICS:current tool mode = pk4
2441 1737967271721 GEN4_CONNECT_DIAGNOSTICS:ENTERING: com.microchip.mplab.mdbcore.pk4hybrid.pk4hybridFirmwareUpdateHandler.GetUpdateInfo()
2441 1737967271725 GEN4_CONNECT_DIAGNOSTICS:Parsing file  for firmware updates
2441 1737967271725 GEN4_CONNECT_DIAGNOSTICS:ENTERING: com.microchip.mplab.mdbcore.pk4hybrid.pk4hybridFirmwareUpdateHandler.ParseSelectedVersionsFromJamFile()
2441 1737967271725 GEN4_CONNECT_DIAGNOSTICS:Jame file line = pkob4_boot.hex,010141
2441 1737967271725 GEN4_CONNECT_DIAGNOSTICS:Jame file line = scripts.xml,000873
2441 1737967271725 GEN4_CONNECT_DIAGNOSTICS:Jame file line = pkob4_app1 000908, 0040C000
2441 1737967271725 GEN4_CONNECT_DIAGNOSTICS:EXITING: com.microchip.mplab.mdbcore.pk4hybrid.pk4hybridFirmwareUpdateHandler.ri4ParseSelectedVersionsFromJamFile()
2441 1737967271725 GEN4_CONNECT_DIAGNOSTICS:EXITING: com.microchip.mplab.mdbcore.pk4hybrid.pk4hybridFirmwareUpdateHandler.GetUpdateInfo()
2441 1737967271725 GEN4_CONNECT_DIAGNOSTICS:current toolType = pk4

2441 1737967271725 GEN4_TO_CONTROLLER_LOG:GEN4_CONNECT_INT_LOG_ATSAME54P20A Pre:EstablishCommunincations
2441 1737967271725 GEN4_TO_CONTROLLER_LOG:GEN4_CONNECT_INT_LOG_ATSAME54P20A Payload
2441 1737967271725 GEN4_TO_CONTROLLER_LOG:GEN4_CONNECT_INT_LOG_ATSAME54P20A com.microchip.mplab.mdbcore.PK4Tool.PK4Com@36f35620
2441 1737967271725 GEN4_TO_CONTROLLER_LOG:GEN4_CONNECT_INT_LOG_ATSAME54P20A Payload End
2441 1737967271725 GEN4_TO_CONTROLLER_LOG:GEN4_CONNECT_INT_LOG_ATSAME54P20A Post:EstablishCommunincations
2441 1737967271725 GEN4_TO_CONTROLLER_LOG:GEN4_CONNECT_INT_LOG_ATSAME54P20A Return Value
2441 1737967271725 GEN4_TO_CONTROLLER_LOG:GEN4_CONNECT_INT_LOG_ATSAME54P20A true
2441 1737967271725 GEN4_TO_CONTROLLER_LOG:GEN4_CONNECT_INT_LOG_ATSAME54P20A Return End

2441 1737967271725 GEN4_TO_CONTROLLER_LOG:GEN4_CONNECT_INT_LOG_ATSAME54P20A Pre:GetFirmwareInfo
2441 1737967271725 GEN4_TO_CONTROLLER_LOG:GEN4_CONNECT_INT_LOG_ATSAME54P20A Payload
2441 1737967271725 GEN4_TO_CONTROLLER_LOG:GEN4_CONNECT_INT_LOG_ATSAME54P20A null
2441 1737967271725 GEN4_TO_CONTROLLER_LOG:GEN4_CONNECT_INT_LOG_ATSAME54P20A Payload End
2441 1737967271734 GEN4_TO_CONTROLLER_LOG:GEN4_CONNECT_INT_LOG_ATSAME54P20A Post:GetFirmwareInfo
2441 1737967271734 GEN4_TO_CONTROLLER_LOG:GEN4_CONNECT_INT_LOG_ATSAME54P20A Return Value
2441 1737967271734 GEN4_TO_CONTROLLER_LOG:GEN4_CONNECT_INT_LOG_ATSAME54P20A FirmwareInfo: Values:
2441 1737967271734 GEN4_TO_CONTROLLER_LOG:GEN4_CONNECT_INT_LOG_ATSAME54P20A FirmwareInfo: boot = false, bootVer = 01.01.41, apVer = 00.09.08, fpgaVer = ff.ff.ff, scriptVer = 00.08.73, macAddress = 0495683578451535048485252484953, devID = a1020e01, devID1 = 1, devSN0 = ffffffff, devSN1 = ffffffff, serialNumber = 020012202RYN000072, appCommitID = null, scriptCommitID = df19a696ae, PCB_ID = 80000000
2441 1737967271734 GEN4_TO_CONTROLLER_LOG:GEN4_CONNECT_INT_LOG_ATSAME54P20A Return End
2441 1737967271909 GEN4_CONNECT_DIAGNOSTICS:appNeedsUpdate returned false
2441 1737967271909 GEN4_CONNECT_DIAGNOSTICS:EXITING: com.microchip.mplab.mdbcore.RI4Tool.ConnectionHandler.CheckForFWUpdates()

2441 1737967271909 GEN4_TO_CONTROLLER_LOG:GEN4_CONNECT_INT_LOG_ATSAME54P20A Pre:EstablishCommunincations
2441 1737967271909 GEN4_TO_CONTROLLER_LOG:GEN4_CONNECT_INT_LOG_ATSAME54P20A Payload
2441 1737967271909 GEN4_TO_CONTROLLER_LOG:GEN4_CONNECT_INT_LOG_ATSAME54P20A com.microchip.mplab.mdbcore.PK4Tool.PK4Com@36f35620
2441 1737967271909 GEN4_TO_CONTROLLER_LOG:GEN4_CONNECT_INT_LOG_ATSAME54P20A Payload End
2441 1737967271911 GEN4_TO_CONTROLLER_LOG:GEN4_CONNECT_INT_LOG_ATSAME54P20A Post:EstablishCommunincations
2441 1737967271911 GEN4_TO_CONTROLLER_LOG:GEN4_CONNECT_INT_LOG_ATSAME54P20A Return Value
2441 1737967271911 GEN4_TO_CONTROLLER_LOG:GEN4_CONNECT_INT_LOG_ATSAME54P20A true
2441 1737967271911 GEN4_TO_CONTROLLER_LOG:GEN4_CONNECT_INT_LOG_ATSAME54P20A Return End

2441 1737967271911 GEN4_TO_CONTROLLER_LOG:GEN4_CONNECT_INT_LOG_ATSAME54P20A Pre:GetFirmwareInfo
2441 1737967271911 GEN4_TO_CONTROLLER_LOG:GEN4_CONNECT_INT_LOG_ATSAME54P20A Payload
2441 1737967271911 GEN4_TO_CONTROLLER_LOG:GEN4_CONNECT_INT_LOG_ATSAME54P20A null
2441 1737967271911 GEN4_TO_CONTROLLER_LOG:GEN4_CONNECT_INT_LOG_ATSAME54P20A Payload End
2441 1737967271918 GEN4_TO_CONTROLLER_LOG:GEN4_CONNECT_INT_LOG_ATSAME54P20A Post:GetFirmwareInfo
2441 1737967271918 GEN4_TO_CONTROLLER_LOG:GEN4_CONNECT_INT_LOG_ATSAME54P20A Return Value
2441 1737967271918 GEN4_TO_CONTROLLER_LOG:GEN4_CONNECT_INT_LOG_ATSAME54P20A FirmwareInfo: Values:
2441 1737967271918 GEN4_TO_CONTROLLER_LOG:GEN4_CONNECT_INT_LOG_ATSAME54P20A FirmwareInfo: boot = false, bootVer = 01.01.41, apVer = 00.09.08, fpgaVer = ff.ff.ff, scriptVer = 00.08.73, macAddress = 0495683578451535048485252484953, devID = a1020e01, devID1 = 1, devSN0 = ffffffff, devSN1 = ffffffff, serialNumber = 020012202RYN000072, appCommitID = null, scriptCommitID = df19a696ae, PCB_ID = 80000000
2441 1737967271918 GEN4_TO_CONTROLLER_LOG:GEN4_CONNECT_INT_LOG_ATSAME54P20A Return End

2441 1737967271919 GEN4_TO_CONTROLLER_LOG:GEN4_CONNECT_INT_LOG_ATSAME54P20A Pre:GetFirmwareInfo
2441 1737967271919 GEN4_TO_CONTROLLER_LOG:GEN4_CONNECT_INT_LOG_ATSAME54P20A Payload
2441 1737967271919 GEN4_TO_CONTROLLER_LOG:GEN4_CONNECT_INT_LOG_ATSAME54P20A null
2441 1737967271919 GEN4_TO_CONTROLLER_LOG:GEN4_CONNECT_INT_LOG_ATSAME54P20A Payload End
2441 1737967271935 GEN4_TO_CONTROLLER_LOG:GEN4_CONNECT_INT_LOG_ATSAME54P20A Post:GetFirmwareInfo
2441 1737967271935 GEN4_TO_CONTROLLER_LOG:GEN4_CONNECT_INT_LOG_ATSAME54P20A Return Value
2441 1737967271935 GEN4_TO_CONTROLLER_LOG:GEN4_CONNECT_INT_LOG_ATSAME54P20A FirmwareInfo: Values:
2441 1737967271935 GEN4_TO_CONTROLLER_LOG:GEN4_CONNECT_INT_LOG_ATSAME54P20A FirmwareInfo: boot = false, bootVer = 01.01.41, apVer = 00.09.08, fpgaVer = ff.ff.ff, scriptVer = 00.08.73, macAddress = 0495683578451535048485252484953, devID = a1020e01, devID1 = 1, devSN0 = ffffffff, devSN1 = ffffffff, serialNumber = 020012202RYN000072, appCommitID = null, scriptCommitID = df19a696ae, PCB_ID = 80000000
2441 1737967271935 GEN4_TO_CONTROLLER_LOG:GEN4_CONNECT_INT_LOG_ATSAME54P20A Return End
2441 1737967271935 GEN4_CONNECT_DIAGNOSTICS:ENTERING: com.microchip.mplab.mdbcore.RI4Tool.ConnectionHandler.CheckForFWUpdates()
2441 1737967271935 GEN4_CONNECT_DIAGNOSTICS:Created FirmwareUpdateHandler com.microchip.mplab.mdbcore.pk4hybrid.pk4hybridFirmwareUpdateHandler@75834ed6
2441 1737967271936 GEN4_CONNECT_DIAGNOSTICS:ENTERING: com.microchip.mplab.mdbcore.pk4hybrid.pk4hybridFirmwareUpdateHandler.UpdateFirmware(FirmwareInfo, UpdateMessage)
2441 1737967271936 GEN4_CONNECT_DIAGNOSTICS:areWeInBoot returned false
2441 1737967271936 GEN4_CONNECT_DIAGNOSTICS:inBoot = false
2441 1737967271936 GEN4_CONNECT_DIAGNOSTICS:uMode = done
2441 1737967271936 GEN4_CONNECT_DIAGNOSTICS:selectedTool = pk4
2441 1737967271936 GEN4_CONNECT_DIAGNOSTICS:current toolType = pk4
2441 1737967271936 GEN4_CONNECT_DIAGNOSTICS:current tool mode = pk4
2441 1737967271936 GEN4_CONNECT_DIAGNOSTICS:ENTERING: com.microchip.mplab.mdbcore.pk4hybrid.pk4hybridFirmwareUpdateHandler.updatePk4HybridFirmware()
2441 1737967271936 GEN4_CONNECT_DIAGNOSTICS:Don't upgrade fimware = false
2441 1737967271936 GEN4_CONNECT_DIAGNOSTICS:ENTERING: com.microchip.mplab.mdbcore.pk4hybrid.pk4hybridFirmwareUpdateHandler.updatePk4HybridFirmware()
2441 1737967271936 GEN4_CONNECT_DIAGNOSTICS:EXITING: com.microchip.mplab.mdbcore.pk4hybrid.pk4hybridFirmwareUpdateHandler.UpdateFirmware(FirmwareInfo, UpdateMessage)
2441 1737967271936 GEN4_CONNECT_DIAGNOSTICS:EXITING: com.microchip.mplab.mdbcore.RI4Tool.ConnectionHandler.CheckForFWUpdates()

2441 1737967271936 GEN4_TO_CONTROLLER_LOG:GEN4_CONNECT_INT_LOG_ATSAME54P20A Pre:SetPowerInfo
2441 1737967271936 GEN4_TO_CONTROLLER_LOG:GEN4_CONNECT_INT_LOG_ATSAME54P20A Payload
2441 1737967271936 GEN4_TO_CONTROLLER_LOG:GEN4_CONNECT_INT_LOG_ATSAME54P20A PowerInfo: Values:
2441 1737967271936 GEN4_TO_CONTROLLER_LOG:GEN4_CONNECT_INT_LOG_ATSAME54P20A PowerInfo: shotDownSystem = false, isToolPower = false, voltage = 3.300000, useVppFirst = false, useLowVoltageProgramming = true, useMaintainActivePower = false
2441 1737967271936 GEN4_TO_CONTROLLER_LOG:GEN4_CONNECT_INT_LOG_ATSAME54P20A Payload End
2441 1737967271936 XXXX 1737967271936, Thread 2441: XXXX 1737967271936, Entering Thread 2441: Commands::runScriptBasic with script contents. contents[0] = 0x39, ...  
2441 1737967271937 XXXX 1737967271937, Thread 2441: XXXX 1737967271937, Exiting Thread 2441: Commands::runScriptBasic  
2441 1737967271937 XXXX 1737967271937, Thread 2441: XXXX 1737967271937, Entering Thread 2441: Commands::runScriptBasic with script contents. contents[0] = 0x46, ...  
2441 1737967271939 XXXX 1737967271939, Thread 2441: XXXX 1737967271939, Exiting Thread 2441: Commands::runScriptBasic  
2441 1737967271939 XXXX 1737967271939, Thread 2441: XXXX 1737967271939, Entering Thread 2441: Commands::runScriptBasic with script contents. contents[0] = 0x44, ...  
2441 1737967271942 XXXX 1737967271942, Thread 2441: XXXX 1737967271942, Exiting Thread 2441: Commands::runScriptBasic  
2441 1737967271942 XXXX 1737967271942, Thread 2441: XXXX 1737967271942, Entering Thread 2441: Commands::runScriptBasic with script contents. contents[0] = 0xef, ...  
2441 1737967271943 XXXX 1737967271943, Thread 2441: XXXX 1737967271943, Exiting Thread 2441: Commands::runScriptBasic  
2441 1737967271943 XXXX 1737967271943, Thread 2441: XXXX 1737967271943, Entering Thread 2441: Commands::runScriptBasic with script contents. contents[0] = 0x40, ...  
2441 1737967271944 XXXX 1737967271944, Thread 2441: XXXX 1737967271944, Exiting Thread 2441: Commands::runScriptBasic  
2441 1737967271944 XXXX 1737967271944, Thread 2441: XXXX 1737967271944, Entering Thread 2441: Commands::runScriptBasic with script contents. contents[0] = 0x47, ...  
2441 1737967271945 XXXX 1737967271945, Thread 2441: XXXX 1737967271945, Exiting Thread 2441: Commands::runScriptBasic  
2441 1737967271945 GEN4_TO_CONTROLLER_LOG:GEN4_CONNECT_INT_LOG_ATSAME54P20A Post:SetPowerInfo
2441 1737967271945 GEN4_TO_CONTROLLER_LOG:GEN4_CONNECT_INT_LOG_ATSAME54P20A Return Value
2441 1737967271945 GEN4_TO_CONTROLLER_LOG:GEN4_CONNECT_INT_LOG_ATSAME54P20A none
2441 1737967271945 GEN4_TO_CONTROLLER_LOG:GEN4_CONNECT_INT_LOG_ATSAME54P20A Return End

2441 1737967271945 GEN4_TO_CONTROLLER_LOG:GEN4_CONNECT_INT_LOG_ATSAME54P20A Pre:GetVoltageInfo
2441 1737967271945 GEN4_TO_CONTROLLER_LOG:GEN4_CONNECT_INT_LOG_ATSAME54P20A Payload
2441 1737967271945 GEN4_TO_CONTROLLER_LOG:GEN4_CONNECT_INT_LOG_ATSAME54P20A null
2441 1737967271945 GEN4_TO_CONTROLLER_LOG:GEN4_CONNECT_INT_LOG_ATSAME54P20A Payload End
2441 1737967271945 XXXX 1737967271945, Thread 2441: XXXX 1737967271945, Entering Thread 2441: Commands::runScriptBasic with script contents. contents[0] = 0x47, ...  
2441 1737967271946 XXXX 1737967271946, Thread 2441: XXXX 1737967271946, Exiting Thread 2441: Commands::runScriptBasic  
2441 1737967271946 GEN4_TO_CONTROLLER_LOG:GEN4_CONNECT_INT_LOG_ATSAME54P20A Post:GetVoltageInfo
2441 1737967271946 GEN4_TO_CONTROLLER_LOG:GEN4_CONNECT_INT_LOG_ATSAME54P20A Return Value
2441 1737967271946 GEN4_TO_CONTROLLER_LOG:GEN4_CONNECT_INT_LOG_ATSAME54P20A VoltagesInfo: Values:
2441 1737967271946 GEN4_TO_CONTROLLER_LOG:GEN4_CONNECT_INT_LOG_ATSAME54P20A VoltagesInfo: internalVdd = 3300, internalVpp = 3300, targetVdd = 3300, targetVpp = 3300, vddSense = 3300, temp = 25000, vddCurrentSense = 0, vddVoltageSense = 3300
2441 1737967271946 GEN4_TO_CONTROLLER_LOG:GEN4_CONNECT_INT_LOG_ATSAME54P20A Return End

2441 1737967271946 GEN4_TO_CONTROLLER_LOG:GEN4_CONNECT_INT_LOG_ATSAME54P20A Pre:GetFirmwareInfo
2441 1737967271946 GEN4_TO_CONTROLLER_LOG:GEN4_CONNECT_INT_LOG_ATSAME54P20A Payload
2441 1737967271946 GEN4_TO_CONTROLLER_LOG:GEN4_CONNECT_INT_LOG_ATSAME54P20A null
2441 1737967271946 GEN4_TO_CONTROLLER_LOG:GEN4_CONNECT_INT_LOG_ATSAME54P20A Payload End
2441 1737967271954 GEN4_TO_CONTROLLER_LOG:GEN4_CONNECT_INT_LOG_ATSAME54P20A Post:GetFirmwareInfo
2441 1737967271954 GEN4_TO_CONTROLLER_LOG:GEN4_CONNECT_INT_LOG_ATSAME54P20A Return Value
2441 1737967271954 GEN4_TO_CONTROLLER_LOG:GEN4_CONNECT_INT_LOG_ATSAME54P20A FirmwareInfo: Values:
2441 1737967271954 GEN4_TO_CONTROLLER_LOG:GEN4_CONNECT_INT_LOG_ATSAME54P20A FirmwareInfo: boot = false, bootVer = 01.01.41, apVer = 00.09.08, fpgaVer = ff.ff.ff, scriptVer = 00.08.73, macAddress = 0495683578451535048485252484953, devID = a1020e01, devID1 = 1, devSN0 = ffffffff, devSN1 = ffffffff, serialNumber = 020012202RYN000072, appCommitID = null, scriptCommitID = df19a696ae, PCB_ID = 80000000
2441 1737967271954 GEN4_TO_CONTROLLER_LOG:GEN4_CONNECT_INT_LOG_ATSAME54P20A Return End

2441 1737967271954 GEN4_TO_CONTROLLER_LOG:GEN4_CONNECT_INT_LOG_ATSAME54P20A Pre:SetToolInfo
2441 1737967271954 GEN4_TO_CONTROLLER_LOG:GEN4_CONNECT_INT_LOG_ATSAME54P20A Payload
2441 1737967271954 GEN4_TO_CONTROLLER_LOG:GEN4_CONNECT_INT_LOG_ATSAME54P20A ToolInfo: Values:
2441 1737967271954 GEN4_TO_CONTROLLER_LOG:GEN4_CONNECT_INT_LOG_ATSAME54P20A ToolInfo: speedLevel = 1, PGCResistance = 4700, PGDResistance = 4700, PGCPullDir = None, PGDPullDir = None, ICSPSelected = Wire2
2441 1737967271954 GEN4_TO_CONTROLLER_LOG:GEN4_CONNECT_INT_LOG_ATSAME54P20A Payload End
2441 1737967271954 XXXX 1737967271954, Thread 2441: XXXX 1737967271954, Entering Thread 2441: Commands::runScriptBasic with script contents. contents[0] = 0x27, ...  
2441 1737967271955 XXXX 1737967271955, Thread 2441: XXXX 1737967271955, Exiting Thread 2441: Commands::runScriptBasic  
2441 1737967271956 XXXX 1737967271956, Thread 2441: XXXX 1737967271956, Entering Thread 2441: Commands::runScriptBasic, script name = SetSpeedFromDevice, timeOut = -1 ms  
2441 1737967271958 XXXX 1737967271958, Thread 2441: XXXX 1737967271958, Exiting Thread 2441: Commands::runScriptBasic  
2441 1737967271958 XXXX 1737967271958, Thread 2441: XXXX 1737967271958, Entering Thread 2441: Commands::runScriptBasic with script contents. contents[0] = 0xed, ...  
2441 1737967271959 XXXX 1737967271959, Thread 2441: XXXX 1737967271959, Exiting Thread 2441: Commands::runScriptBasic  
2441 1737967271959 XXXX 1737967271959, Thread 2441: XXXX 1737967271959, Entering Thread 2441: Commands::runScriptBasic with script contents. contents[0] = 0x3b, ...  
2441 1737967271960 XXXX 1737967271960, Thread 2441: XXXX 1737967271960, Exiting Thread 2441: Commands::runScriptBasic  
2441 1737967271960 XXXX 1737967271960, Thread 2441: XXXX 1737967271960, Entering Thread 2441: Commands::runScriptBasic with script contents. contents[0] = 0xd4, ...  
2441 1737967271961 XXXX 1737967271961, Thread 2441: XXXX 1737967271961, Exiting Thread 2441: Commands::runScriptBasic  
2441 1737967271961 GEN4_TO_CONTROLLER_LOG:GEN4_CONNECT_INT_LOG_ATSAME54P20A Post:SetToolInfo
2441 1737967271961 GEN4_TO_CONTROLLER_LOG:GEN4_CONNECT_INT_LOG_ATSAME54P20A Return Value
2441 1737967271961 GEN4_TO_CONTROLLER_LOG:GEN4_CONNECT_INT_LOG_ATSAME54P20A none
2441 1737967271961 GEN4_TO_CONTROLLER_LOG:GEN4_CONNECT_INT_LOG_ATSAME54P20A Return End

2441 1737967271997 GEN4_TO_CONTROLLER_LOG:GEN4_CONNECT_INT_LOG_ATSAME54P20A Pre:GetTargetIDInfo
2441 1737967271997 GEN4_TO_CONTROLLER_LOG:GEN4_CONNECT_INT_LOG_ATSAME54P20A Payload
2441 1737967271997 GEN4_TO_CONTROLLER_LOG:GEN4_CONNECT_INT_LOG_ATSAME54P20A null
2441 1737967271997 GEN4_TO_CONTROLLER_LOG:GEN4_CONNECT_INT_LOG_ATSAME54P20A Payload End
2441 1737967271999 XXXX 1737967271999, Thread 2441: XXXX 1737967271999, Entering Thread 2441: Commands::runScriptBasic, script name = InitSWD, timeOut = -1 ms  
2441 1737967272015 XXXX 1737967272015, Thread 2441: XXXX 1737967272015, Exiting Thread 2441: Commands::runScriptBasic  
2441 1737967272015 XXXX 1737967272015, Thread 2441: XXXX 1737967272015, Entering Thread 2441: Commands::runScriptBasic, script name = GetDeviceID, timeOut = -1 ms  
2441 1737967272016 XXXX 1737967272016, Thread 2441: XXXX 1737967272016, Exiting Thread 2441: Commands::runScriptBasic  
2441 1737967272016 GEN4_TO_CONTROLLER_LOG:GEN4_CONNECT_INT_LOG_ATSAME54P20A Post:GetTargetIDInfo
2441 1737967272016 GEN4_TO_CONTROLLER_LOG:GEN4_CONNECT_INT_LOG_ATSAME54P20A Return Value
2441 1737967272016 GEN4_TO_CONTROLLER_LOG:GEN4_CONNECT_INT_LOG_ATSAME54P20A TargetIDInfo: Values:
2441 1737967272016 GEN4_TO_CONTROLLER_LOG:GEN4_CONNECT_INT_LOG_ATSAME54P20A TargetIDInfo: DeviceID = 61840000
2441 1737967272016 GEN4_TO_CONTROLLER_LOG:GEN4_CONNECT_INT_LOG_ATSAME54P20A Return End

2441 1737967272305 GEN4_TO_CONTROLLER_LOG:GEN4_PROGRAM_INT_LOG_ATSAME54P20A Pre:SendOperation
2441 1737967272305 GEN4_TO_CONTROLLER_LOG:GEN4_PROGRAM_INT_LOG_ATSAME54P20A Payload
2441 1737967272305 GEN4_TO_CONTROLLER_LOG:GEN4_PROGRAM_INT_LOG_ATSAME54P20A OperationInfo: Values:
2441 1737967272305 GEN4_TO_CONTROLLER_LOG:GEN4_PROGRAM_INT_LOG_ATSAME54P20A OperationInfo: Type = erase, Mask = 00000000, Erase = false, Production Mode = true
2441 1737967272305 GEN4_TO_CONTROLLER_LOG:GEN4_PROGRAM_INT_LOG_ATSAME54P20A TransferInfo: Start = 0, End = fffff, Buffer Length = 0, Type = Pgm, Mask = 00000000
2441 1737967272305 GEN4_TO_CONTROLLER_LOG:GEN4_PROGRAM_INT_LOG_ATSAME54P20A TransferInfo: Start = 4000000, End = 4ffffff, Buffer Length = 0, Type = Pgm, Mask = 00000000
2441 1737967272305 GEN4_TO_CONTROLLER_LOG:GEN4_PROGRAM_INT_LOG_ATSAME54P20A TransferInfo: Start = 804000, End = 80400b, Buffer Length = 0, Type = Cfg, Mask = 00000000
2441 1737967272305 GEN4_TO_CONTROLLER_LOG:GEN4_PROGRAM_INT_LOG_ATSAME54P20A TransferInfo: Start = 80400c, End = 8041ff, Buffer Length = 0, Type = UserID, Mask = 00000000
2441 1737967272305 GEN4_TO_CONTROLLER_LOG:GEN4_PROGRAM_INT_LOG_ATSAME54P20A TransferInfo: Start = 20000000, End = 2003ffff, Buffer Length = 0, Type = FileRegs, Mask = 00000000
2441 1737967272305 GEN4_TO_CONTROLLER_LOG:GEN4_PROGRAM_INT_LOG_ATSAME54P20A TransferInfo: Start = 47000000, End = 47001fff, Buffer Length = 0, Type = FileRegs, Mask = 00000000
2441 1737967272305 GEN4_TO_CONTROLLER_LOG:GEN4_PROGRAM_INT_LOG_ATSAME54P20A Payload End
2441 1737967272305 XXXX 1737967272305, Thread 2441: XXXX 1737967272305, Entering Thread 2441: Commands::runScriptBasic, script name = EraseChip, timeOut = -1 ms  
2441 1737967277229 XXXX 1737967277229, Thread 2441: XXXX 1737967277229, Exiting Thread 2441: Commands::runScriptBasic  
2441 1737967277229 GEN4_TO_CONTROLLER_LOG:GEN4_PROGRAM_INT_LOG_ATSAME54P20A Post:SendOperation
2441 1737967277229 GEN4_TO_CONTROLLER_LOG:GEN4_PROGRAM_INT_LOG_ATSAME54P20A Return Value
2441 1737967277229 GEN4_TO_CONTROLLER_LOG:GEN4_PROGRAM_INT_LOG_ATSAME54P20A None
2441 1737967277229 GEN4_TO_CONTROLLER_LOG:GEN4_PROGRAM_INT_LOG_ATSAME54P20A Return End

2441 1737967277271 GEN4_TO_CONTROLLER_LOG:GEN4_PROGRAM_INT_LOG_ATSAME54P20A Pre:SendOperation
2441 1737967277271 GEN4_TO_CONTROLLER_LOG:GEN4_PROGRAM_INT_LOG_ATSAME54P20A Payload
2441 1737967277271 GEN4_TO_CONTROLLER_LOG:GEN4_PROGRAM_INT_LOG_ATSAME54P20A OperationInfo: Values:
2441 1737967277271 GEN4_TO_CONTROLLER_LOG:GEN4_PROGRAM_INT_LOG_ATSAME54P20A OperationInfo: Type = read, Mask = 00000000, Erase = false, Production Mode = true
2441 1737967277271 GEN4_TO_CONTROLLER_LOG:GEN4_PROGRAM_INT_LOG_ATSAME54P20A TransferInfo: Start = 804000, End = 8041ff, Buffer Length = 512, Type = Cfg, Mask = 00000002
2441 1737967277271 GEN4_TO_CONTROLLER_LOG:GEN4_PROGRAM_INT_LOG_ATSAME54P20A Payload End
2441 1737967277271 XXXX 1737967277271, Thread 2441: XXXX 1737967277271, Entering Thread 2441: Commands::runScriptWithUpload, script name = ReadConfigmem  
2441 1737967277271 XXXX 1737967277271, Thread 2441: XXXX 1737967277271, Entering Thread 2441: ToolCommUsb::readTransfer, sideData is 0x24 bytes long, transferDataLength is 0x200 bytes long  
2441 1737967277280 XXXX 1737967277280, Thread 2441: XXXX 1737967277280, Exiting Thread 2441: ToolCommUsb::readTransfer,  cr.status = 0x0  
2441 1737967277280 XXXX 1737967277280, Thread 2441: XXXX 1737967277280, Exiting Thread 2441: Commands::runScriptWithUpload  
2441 1737967277281 GEN4_TO_CONTROLLER_LOG:GEN4_PROGRAM_INT_LOG_ATSAME54P20A Post:SendOperation
2441 1737967277281 GEN4_TO_CONTROLLER_LOG:GEN4_PROGRAM_INT_LOG_ATSAME54P20A Return Value
2441 1737967277281 GEN4_TO_CONTROLLER_LOG:GEN4_PROGRAM_INT_LOG_ATSAME54P20A None
2441 1737967277281 GEN4_TO_CONTROLLER_LOG:GEN4_PROGRAM_INT_LOG_ATSAME54P20A Return End

2441 1737967277281 GEN4_TO_CONTROLLER_LOG:GEN4_PROGRAM_INT_LOG_ATSAME54P20A Pre:SendOperation
2441 1737967277281 GEN4_TO_CONTROLLER_LOG:GEN4_PROGRAM_INT_LOG_ATSAME54P20A Payload
2441 1737967277281 GEN4_TO_CONTROLLER_LOG:GEN4_PROGRAM_INT_LOG_ATSAME54P20A OperationInfo: Values:
2441 1737967277281 GEN4_TO_CONTROLLER_LOG:GEN4_PROGRAM_INT_LOG_ATSAME54P20A OperationInfo: Type = read, Mask = 00000000, Erase = false, Production Mode = true
2441 1737967277281 GEN4_TO_CONTROLLER_LOG:GEN4_PROGRAM_INT_LOG_ATSAME54P20A Payload End
2441 1737967277281 GEN4_TO_CONTROLLER_LOG:GEN4_PROGRAM_INT_LOG_ATSAME54P20A Post:SendOperation
2441 1737967277281 GEN4_TO_CONTROLLER_LOG:GEN4_PROGRAM_INT_LOG_ATSAME54P20A Return Value
2441 1737967277281 GEN4_TO_CONTROLLER_LOG:GEN4_PROGRAM_INT_LOG_ATSAME54P20A None
2441 1737967277281 GEN4_TO_CONTROLLER_LOG:GEN4_PROGRAM_INT_LOG_ATSAME54P20A Return End

2441 1737967277288 GEN4_TO_CONTROLLER_LOG:GEN4_PROGRAM_INT_LOG_ATSAME54P20A Pre:SendOperation
2441 1737967277288 GEN4_TO_CONTROLLER_LOG:GEN4_PROGRAM_INT_LOG_ATSAME54P20A Payload
2441 1737967277288 GEN4_TO_CONTROLLER_LOG:GEN4_PROGRAM_INT_LOG_ATSAME54P20A OperationInfo: Values:
2441 1737967277288 GEN4_TO_CONTROLLER_LOG:GEN4_PROGRAM_INT_LOG_ATSAME54P20A OperationInfo: Type = read, Mask = 00000000, Erase = false, Production Mode = true
2441 1737967277288 GEN4_TO_CONTROLLER_LOG:GEN4_PROGRAM_INT_LOG_ATSAME54P20A TransferInfo: Start = 804000, End = 8041ff, Buffer Length = 512, Type = Cfg, Mask = 00000002
2441 1737967277288 GEN4_TO_CONTROLLER_LOG:GEN4_PROGRAM_INT_LOG_ATSAME54P20A Payload End
2441 1737967277289 XXXX 1737967277289, Thread 2441: XXXX 1737967277289, Entering Thread 2441: Commands::runScriptWithUpload, script name = ReadConfigmem  
2441 1737967277289 XXXX 1737967277289, Thread 2441: XXXX 1737967277289, Entering Thread 2441: ToolCommUsb::readTransfer, sideData is 0x24 bytes long, transferDataLength is 0x200 bytes long  
2441 1737967277302 XXXX 1737967277302, Thread 2441: XXXX 1737967277302, Exiting Thread 2441: ToolCommUsb::readTransfer,  cr.status = 0x0  
2441 1737967277302 XXXX 1737967277302, Thread 2441: XXXX 1737967277302, Exiting Thread 2441: Commands::runScriptWithUpload  
2441 1737967277302 GEN4_TO_CONTROLLER_LOG:GEN4_PROGRAM_INT_LOG_ATSAME54P20A Post:SendOperation
2441 1737967277302 GEN4_TO_CONTROLLER_LOG:GEN4_PROGRAM_INT_LOG_ATSAME54P20A Return Value
2441 1737967277302 GEN4_TO_CONTROLLER_LOG:GEN4_PROGRAM_INT_LOG_ATSAME54P20A None
2441 1737967277302 GEN4_TO_CONTROLLER_LOG:GEN4_PROGRAM_INT_LOG_ATSAME54P20A Return End

2441 1737967277302 GEN4_TO_CONTROLLER_LOG:GEN4_PROGRAM_INT_LOG_ATSAME54P20A Pre:SendOperation
2441 1737967277302 GEN4_TO_CONTROLLER_LOG:GEN4_PROGRAM_INT_LOG_ATSAME54P20A Payload
2441 1737967277302 GEN4_TO_CONTROLLER_LOG:GEN4_PROGRAM_INT_LOG_ATSAME54P20A OperationInfo: Values:
2441 1737967277302 GEN4_TO_CONTROLLER_LOG:GEN4_PROGRAM_INT_LOG_ATSAME54P20A OperationInfo: Type = write, Mask = 00000000, Erase = false, Production Mode = true
2441 1737967277302 GEN4_TO_CONTROLLER_LOG:GEN4_PROGRAM_INT_LOG_ATSAME54P20A TransferInfo: Start = 0, End = 61fff, Buffer Length = 401408, Type = Pgm, Mask = 00000000
2441 1737967277302 GEN4_TO_CONTROLLER_LOG:GEN4_PROGRAM_INT_LOG_ATSAME54P20A TransferInfo: Start = 804000, End = 8041ff, Buffer Length = 512, Type = Cfg, Mask = 00000002
2441 1737967277302 GEN4_TO_CONTROLLER_LOG:GEN4_PROGRAM_INT_LOG_ATSAME54P20A TransferInfo: Start = 20002000, End = 20003fff, Buffer Length = 8192, Type = FileRegs, Mask = 00000000
2441 1737967277302 GEN4_TO_CONTROLLER_LOG:GEN4_PROGRAM_INT_LOG_ATSAME54P20A Payload End
2441 1737967277302 XXXX 1737967277302, Thread 2441: XXXX 1737967277302, Entering Thread 2441: Commands::runScriptWithDownload, script name = WriteProgmem  
2441 1737967282040 XXXX 1737967282040, Thread 2441: XXXX 1737967282040, Exiting Thread 2441: Commands::runScriptWithDownload(WriteProgmem)  
2441 1737967282040 XXXX 1737967282040, Thread 2441: XXXX 1737967282040, Entering Thread 2441: Commands::runScriptWithUpload, script name = ReadProgmem  
2441 1737967282040 XXXX 1737967282040, Thread 2441: XXXX 1737967282040, Entering Thread 2441: ToolCommUsb::readTransfer, sideData is 0x24 bytes long, transferDataLength is 0x62000 bytes long  
2441 1737967285399 XXXX 1737967285399, Thread 2441: XXXX 1737967285399, Exiting Thread 2441: ToolCommUsb::readTransfer,  cr.status = 0x0  
2441 1737967285399 XXXX 1737967285399, Thread 2441: XXXX 1737967285399, Exiting Thread 2441: Commands::runScriptWithUpload  
2441 1737967285400 XXXX 1737967285400, Thread 2441: XXXX 1737967285400, Entering Thread 2441: Commands::runScriptBasic, script name = EraseConfigmem, timeOut = -1 ms  
2441 1737967285410 XXXX 1737967285410, Thread 2441: XXXX 1737967285410, Exiting Thread 2441: Commands::runScriptBasic  
2441 1737967285410 XXXX 1737967285410, Thread 2441: XXXX 1737967285410, Entering Thread 2441: Commands::runScriptWithDownload, script name = WriteConfigmem  
2441 1737967285426 XXXX 1737967285426, Thread 2441: XXXX 1737967285426, Exiting Thread 2441: Commands::runScriptWithDownload(WriteConfigmem)  
2441 1737967285426 XXXX 1737967285426, Thread 2441: XXXX 1737967285426, Entering Thread 2441: Commands::runScriptWithUpload, script name = ReadConfigmem  
2441 1737967285426 XXXX 1737967285426, Thread 2441: XXXX 1737967285426, Entering Thread 2441: ToolCommUsb::readTransfer, sideData is 0x24 bytes long, transferDataLength is 0x200 bytes long  
2441 1737967285433 XXXX 1737967285433, Thread 2441: XXXX 1737967285433, Exiting Thread 2441: ToolCommUsb::readTransfer,  cr.status = 0x0  
2441 1737967285433 XXXX 1737967285433, Thread 2441: XXXX 1737967285433, Exiting Thread 2441: Commands::runScriptWithUpload  
2441 1737967285433 XXXX 1737967285433, Thread 2441: XXXX 1737967285433, Entering Thread 2441: Commands::runScriptWithDownload, script name = WriteEmu  
2441 1737967285505 XXXX 1737967285505, Thread 2441: XXXX 1737967285505, Exiting Thread 2441: Commands::runScriptWithDownload(WriteEmu)  
2441 1737967285505 XXXX 1737967285505, Thread 2441: XXXX 1737967285505, Entering Thread 2441: Commands::runScriptWithUpload, script name = ReadEmu  
2441 1737967285505 XXXX 1737967285505, Thread 2441: XXXX 1737967285505, Entering Thread 2441: ToolCommUsb::readTransfer, sideData is 0x24 bytes long, transferDataLength is 0x2000 bytes long  
2441 1737967285575 XXXX 1737967285575, Thread 2441: XXXX 1737967285575, Exiting Thread 2441: ToolCommUsb::readTransfer,  cr.status = 0x0  
2441 1737967285575 XXXX 1737967285575, Thread 2441: XXXX 1737967285575, Exiting Thread 2441: Commands::runScriptWithUpload  
2441 1737967285575 GEN4_TO_CONTROLLER_LOG:GEN4_PROGRAM_INT_LOG_ATSAME54P20A Post:SendOperation
2441 1737967285575 GEN4_TO_CONTROLLER_LOG:GEN4_PROGRAM_INT_LOG_ATSAME54P20A Return Value
2441 1737967285575 GEN4_TO_CONTROLLER_LOG:GEN4_PROGRAM_INT_LOG_ATSAME54P20A None
2441 1737967285575 GEN4_TO_CONTROLLER_LOG:GEN4_PROGRAM_INT_LOG_ATSAME54P20A Return End

2441 1737967285575 GEN4_TO_CONTROLLER_LOG:GEN4_PROGRAM_INT_LOG_ATSAME54P20A Pre:endOfOperations
2441 1737967285575 GEN4_TO_CONTROLLER_LOG:GEN4_PROGRAM_INT_LOG_ATSAME54P20A Payload
2441 1737967285575 GEN4_TO_CONTROLLER_LOG:GEN4_PROGRAM_INT_LOG_ATSAME54P20A null
2441 1737967285575 GEN4_TO_CONTROLLER_LOG:GEN4_PROGRAM_INT_LOG_ATSAME54P20A Payload End
2441 1737967285575 GEN4_TO_CONTROLLER_LOG:GEN4_PROGRAM_INT_LOG_ATSAME54P20A Post:endOfOperations
2441 1737967285575 GEN4_TO_CONTROLLER_LOG:GEN4_PROGRAM_INT_LOG_ATSAME54P20A Return Value
2441 1737967285575 GEN4_TO_CONTROLLER_LOG:GEN4_PROGRAM_INT_LOG_ATSAME54P20A None
2441 1737967285575 GEN4_TO_CONTROLLER_LOG:GEN4_PROGRAM_INT_LOG_ATSAME54P20A Return End

2441 1737967285593 GEN4_TO_CONTROLLER_LOG:GEN4_PROGRAM_INT_LOG_ATSAME54P20A Pre:SendOperation
2441 1737967285593 GEN4_TO_CONTROLLER_LOG:GEN4_PROGRAM_INT_LOG_ATSAME54P20A Payload
2441 1737967285593 GEN4_TO_CONTROLLER_LOG:GEN4_PROGRAM_INT_LOG_ATSAME54P20A OperationInfo: Values:
2441 1737967285593 GEN4_TO_CONTROLLER_LOG:GEN4_PROGRAM_INT_LOG_ATSAME54P20A OperationInfo: Type = releasefromreset, Mask = 00000000, Erase = false, Production Mode = true
2441 1737967285593 GEN4_TO_CONTROLLER_LOG:GEN4_PROGRAM_INT_LOG_ATSAME54P20A Payload End
2441 1737967285593 XXXX 1737967285593, Thread 2441: XXXX 1737967285593, Entering Thread 2441: Commands::runScriptBasic, script name = UnInitSWD, timeOut = -1 ms  
2441 1737967285595 XXXX 1737967285595, Thread 2441: XXXX 1737967285595, Exiting Thread 2441: Commands::runScriptBasic  
2441 1737967285595 XXXX 1737967285595, Thread 2441: XXXX 1737967285595, Entering Thread 2441: Commands::runScriptBasic with script contents. contents[0] = 0xb1, ...  
2441 1737967285597 XXXX 1737967285597, Thread 2441: XXXX 1737967285597, Exiting Thread 2441: Commands::runScriptBasic  
2441 1737967285597 XXXX 1737967285597, Thread 2441: XXXX 1737967285597, Entering Thread 2441: Commands::runScriptBasic with script contents. contents[0] = 0xef, ...  
2441 1737967285598 XXXX 1737967285598, Thread 2441: XXXX 1737967285598, Exiting Thread 2441: Commands::runScriptBasic  
2441 1737967285598 GEN4_TO_CONTROLLER_LOG:GEN4_PROGRAM_INT_LOG_ATSAME54P20A Post:SendOperation
2441 1737967285598 GEN4_TO_CONTROLLER_LOG:GEN4_PROGRAM_INT_LOG_ATSAME54P20A Return Value
2441 1737967285598 GEN4_TO_CONTROLLER_LOG:GEN4_PROGRAM_INT_LOG_ATSAME54P20A None
2441 1737967285598 GEN4_TO_CONTROLLER_LOG:GEN4_PROGRAM_INT_LOG_ATSAME54P20A Return End
2441 1737967285599 GEN4_CONNECT_DIAGNOSTICS:MPLABCommTool is null

2441 1737967285599 GEN4_TO_CONTROLLER_LOG:GEN4_CONNECT_INT_LOG_ATSAME54P20A Pre:GetFirmwareInfo
2441 1737967285599 GEN4_TO_CONTROLLER_LOG:GEN4_CONNECT_INT_LOG_ATSAME54P20A Payload
2441 1737967285599 GEN4_TO_CONTROLLER_LOG:GEN4_CONNECT_INT_LOG_ATSAME54P20A null
2441 1737967285599 GEN4_TO_CONTROLLER_LOG:GEN4_CONNECT_INT_LOG_ATSAME54P20A Payload End
2441 1737967285607 GEN4_TO_CONTROLLER_LOG:GEN4_CONNECT_INT_LOG_ATSAME54P20A Post:GetFirmwareInfo
2441 1737967285607 GEN4_TO_CONTROLLER_LOG:GEN4_CONNECT_INT_LOG_ATSAME54P20A Return Value
2441 1737967285607 GEN4_TO_CONTROLLER_LOG:GEN4_CONNECT_INT_LOG_ATSAME54P20A FirmwareInfo: Values:
2441 1737967285607 GEN4_TO_CONTROLLER_LOG:GEN4_CONNECT_INT_LOG_ATSAME54P20A FirmwareInfo: boot = false, bootVer = 01.01.41, apVer = 00.09.08, fpgaVer = ff.ff.ff, scriptVer = 00.08.73, macAddress = 0495683578451535048485252484953, devID = a1020e01, devID1 = 1, devSN0 = ffffffff, devSN1 = ffffffff, serialNumber = 020012202RYN000072, appCommitID = null, scriptCommitID = df19a696ae, PCB_ID = 80000000
2441 1737967285607 GEN4_TO_CONTROLLER_LOG:GEN4_CONNECT_INT_LOG_ATSAME54P20A Return End

2441 1737967285607 GEN4_TO_CONTROLLER_LOG:GEN4_CONNECT_INT_LOG_ATSAME54P20A Pre:SetPowerInfo
2441 1737967285607 GEN4_TO_CONTROLLER_LOG:GEN4_CONNECT_INT_LOG_ATSAME54P20A Payload
2441 1737967285607 GEN4_TO_CONTROLLER_LOG:GEN4_CONNECT_INT_LOG_ATSAME54P20A PowerInfo: Values:
2441 1737967285607 GEN4_TO_CONTROLLER_LOG:GEN4_CONNECT_INT_LOG_ATSAME54P20A PowerInfo: shotDownSystem = false, isToolPower = false, voltage = 3.300000, useVppFirst = false, useLowVoltageProgramming = true, useMaintainActivePower = false
2441 1737967285607 GEN4_TO_CONTROLLER_LOG:GEN4_CONNECT_INT_LOG_ATSAME54P20A Payload End
2441 1737967285607 XXXX 1737967285607, Thread 2441: XXXX 1737967285607, Entering Thread 2441: Commands::runScriptBasic with script contents. contents[0] = 0x39, ...  
2441 1737967285609 XXXX 1737967285609, Thread 2441: XXXX 1737967285609, Exiting Thread 2441: Commands::runScriptBasic  
2441 1737967285609 XXXX 1737967285609, Thread 2441: XXXX 1737967285609, Entering Thread 2441: Commands::runScriptBasic with script contents. contents[0] = 0x46, ...  
2441 1737967285610 XXXX 1737967285610, Thread 2441: XXXX 1737967285610, Exiting Thread 2441: Commands::runScriptBasic  
2441 1737967285610 XXXX 1737967285610, Thread 2441: XXXX 1737967285610, Entering Thread 2441: Commands::runScriptBasic with script contents. contents[0] = 0x44, ...  
2441 1737967285611 XXXX 1737967285611, Thread 2441: XXXX 1737967285611, Exiting Thread 2441: Commands::runScriptBasic  
2441 1737967285611 XXXX 1737967285611, Thread 2441: XXXX 1737967285611, Entering Thread 2441: Commands::runScriptBasic with script contents. contents[0] = 0xef, ...  
2441 1737967285612 XXXX 1737967285612, Thread 2441: XXXX 1737967285612, Exiting Thread 2441: Commands::runScriptBasic  
2441 1737967285612 XXXX 1737967285612, Thread 2441: XXXX 1737967285612, Entering Thread 2441: Commands::runScriptBasic with script contents. contents[0] = 0x40, ...  
2441 1737967285612 XXXX 1737967285612, Thread 2441: XXXX 1737967285612, Exiting Thread 2441: Commands::runScriptBasic  
2441 1737967285612 XXXX 1737967285612, Thread 2441: XXXX 1737967285612, Entering Thread 2441: Commands::runScriptBasic with script contents. contents[0] = 0x47, ...  
2441 1737967285614 XXXX 1737967285614, Thread 2441: XXXX 1737967285614, Exiting Thread 2441: Commands::runScriptBasic  
2441 1737967285614 GEN4_TO_CONTROLLER_LOG:GEN4_CONNECT_INT_LOG_ATSAME54P20A Post:SetPowerInfo
2441 1737967285614 GEN4_TO_CONTROLLER_LOG:GEN4_CONNECT_INT_LOG_ATSAME54P20A Return Value
2441 1737967285614 GEN4_TO_CONTROLLER_LOG:GEN4_CONNECT_INT_LOG_ATSAME54P20A none
2441 1737967285614 GEN4_TO_CONTROLLER_LOG:GEN4_CONNECT_INT_LOG_ATSAME54P20A Return End
2441 1737967285614 GEN4_CONNECT_DIAGNOSTICS:Removing plug and play observer com.microchip.mplab.mdbcore.RI4Tool.RI4ToolBase$RI4PlugNPlayObserver@67916f58
2441 1737967285614 GEN4_CONNECT_DIAGNOSTICS:Begin PlugNPlayObservers list dump:
2441 1737967285614 GEN4_CONNECT_DIAGNOSTICS:End PlugNPlayObservers list dump:
2441 1737967285664 GEN4_CONNECT_DIAGNOSTICS:Calling RIDbgToolCom.Disconnect
2441 1737967285664 GEN4_CONNECT_DIAGNOSTICS:Calling MPLABCommTool.Detach to remove tool from plug and play list
2441 1737967285664 GEN4_CONNECT_DIAGNOSTICS:Calling RIDbgToolCom.DisconnectFromMPlabComm
2441 1737967285664 GEN4_CONNECT_DIAGNOSTICS:Calling MPLABCommTool.Disconnect
2995 1737967799010 GEN4_CONNECT_DIAGNOSTICS:MPLABCommTool is NOT null
2995 1737967799010 GEN4_CONNECT_DIAGNOSTICS:AttachedToolPID = 810b, AttachedToolVID = 4d8
2995 1737967799010 GEN4_CONNECT_DIAGNOSTICS:transport type = USB
2995 1737967799010 GEN4_CONNECT_DIAGNOSTICS:AttachedToolPID = 810b, AttachedToolVID = 4d8
2995 1737967799058 com.microchip.mplab.mdbcore.RealICETool.RIDbgToolCom
2995 1737967799058 GEN4_CONNECT_DIAGNOSTICS:Before MPLABCommTool.Connect()
2995 1737967799058 GEN4_CONNECT_DIAGNOSTICS:After MPLABCommTool.Connect()
2995 1737967799058 GEN4_CONNECT_DIAGNOSTICS:MPLABCommTool.Connect() returned MPLABCOMM_NO_ERROR
2995 1737967799058 GEN4_CONNECT_DIAGNOSTICS:Attaching to MPLABCommTool plugnplay
2995 1737967799058 GEN4_CONNECT_DIAGNOSTICS:Adding new plug and play observer com.microchip.mplab.mdbcore.RI4Tool.RI4ToolBase$RI4PlugNPlayObserver@3cf627a3
2995 1737967799058 GEN4_CONNECT_DIAGNOSTICS:Begin PlugNPlayObservers list dump:
2995 1737967799058 GEN4_CONNECT_DIAGNOSTICS:com.microchip.mplab.mdbcore.RI4Tool.RI4ToolBase$RI4PlugNPlayObserver@3cf627a3
2995 1737967799058 GEN4_CONNECT_DIAGNOSTICS:End PlugNPlayObservers list dump:
2995 1737967799058 GEN4_CONNECT_DIAGNOSTICS:Registering for alternate PNP notifications. CommPnPCriteria.cPIDList = [810A, 8109, 2184], CommPnPCriteria.cSerialNumber = 020012202ryn000072
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

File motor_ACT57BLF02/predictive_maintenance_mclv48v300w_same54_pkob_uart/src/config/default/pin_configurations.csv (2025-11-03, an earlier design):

Pin Number | Pin ID | Custom Name | Function | Mode | Direction | Latch | Pull Up | Pull Down | Drive Strength
1 | PA00 |  | Available |  |  |  |  |  | NORMAL
2 | PA01 |  | Available |  |  |  |  |  | NORMAL
3 | PC00 |  | Available |  |  |  |  |  | NORMAL
4 | PC01 |  | Available |  |  |  |  |  | NORMAL
7 | PC02 |  | Available |  |  |  |  |  | NORMAL
8 | PC03 |  | Available |  |  |  |  |  | NORMAL
9 | PA02 | IA | ADC0_AIN0 | Analog | High Impedance | n/a |  |  | NORMAL
10 | PA03 |  | Available |  |  |  |  |  | NORMAL
11 | PB04 |  | Available |  |  |  |  |  | NORMAL
12 | PB05 |  | Available |  |  |  |  |  | NORMAL
13 | PD00 |  | Available |  |  |  |  |  | NORMAL
16 | PD01 |  | Available |  |  |  |  |  | NORMAL
17 | PB06 |  | Available |  |  |  |  |  | NORMAL
18 | PB07 |  | Available |  |  |  |  |  | NORMAL
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

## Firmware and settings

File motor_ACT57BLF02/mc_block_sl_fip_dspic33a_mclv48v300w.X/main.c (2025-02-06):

/* 
 * File:   main.c
 * Author: M91456
 *
 * Created on 7. Februar 2024, 11:55
 */

#include "xc.h"
#include <stdio.h>
#include <stdlib.h>

#include "hal/board_service.h"
#include "hal/clock.h"
#include "hal/port_config.h"
#include "hal/uart1.h"
#include "hal/pwm.h"
#include "hal/timer1.h"
#include "hal/adc.h"
#include "hal/sccp.h"
#include "x2cscope/diagnostics.h"



const uint16_t PWM_STATE1[8] = {0x3000, 0x3400, 0x3000, 0x1000, 0x1000, 0x3000, 0x3400, 0x3000};
const uint16_t PWM_STATE2[8] = {0x3000, 0x3000, 0x3400, 0x3400, 0x3000, 0x1000, 0x1000, 0x3000};
const uint16_t PWM_STATE3[8] = {0x3000, 0x1000, 0x1000, 0x3000, 0x3400, 0x3400, 0x3000, 0x3000};
const uint16_t CommutationSector[8] = {0, 1, 5, 6, 3, 2, 4, 0};

/*AND & OR operators for masking the active BEMF signal*/
const unsigned int ADC_MASK[8] = {0x0000, 0x0002, 0x0001, 0x0004, 0x0002, 0x0001, 0x0004, 0x0000};
const unsigned int ADC_XOR[8] = {0x0000, 0x0000, 0xFFFF, 0x0000, 0xFFFF, 0x0000, 0xFFFF, 0x0000};

/*BEMF Majority Function Filter values*/
const unsigned char ADC_BEMF_FILTER[64] = {
    0x00, 0x02, 0x04, 0x06, 0x08, 0x0A, 0x0C, 0x0E, 0x10, 0x12, 0x14, 0x16, 0x18, 0x1A, 0x1C, 0x1E,
    0x20, 0x22, 0x24, 0x26, 0x28, 0x2A, 0x2C, 0x2E, 0x01, 0x01, 0x01, 0x36, 0x01, 0x3A, 0x3C, 0x3E,
    0x00, 0x02, 0x04, 0x06, 0x08, 0x0A, 0x0C, 0x0E, 0x01, 0x01, 0x01, 0x16, 0x01, 0x1A, 0x1C, 0x1E,
    0x01, 0x01, 0x01, 0x26, 0x01, 0x2A, 0x2C, 0x2E, 0x01, 0x01, 0x01, 0x36, 0x01, 0x3A, 0x3C, 0x3E};

#define MAX_PWM_TICKS 2000 		//for detecting initial rotor position
#define MAX_STARTUP_CNT 10       // Number of Turns for startup
#define RAM_UP_DELAY  0    	 	// Delay for the ramp up sequence, expressed in millisecond
#define ONE_MS      391
#define MIN_PERIOD  5
#define MAX_PERIOD  50
#define STARTUP_DUTY    2000
#define PHASE_ADVANCE_DEGREES 12//Phase advance angles to get the best motor performance
#define BLANKING_COUNT 3		//Blanking count expressed in PWM periods used to avoid false zero-crossing detection after commutating motor
#define ROTOR_POSITION_FLT 5
/*Application Flags to indicate the motor status*/
struct
{
    unsigned RunMotor : 1;
    unsigned RotorAlignment : 1;
    unsigned unused : 14;
} Flags;

uint16_t DutyCycle=MIN_DUTY;
uint16_t OnOff=0;

uint16_t CommutationIdx = 0;
uint16_t CommutationTime;
uint32_t Timer2Value_neu;
uint32_t Timer2Value_alt;
uint32_t Timer2Average;
uint32_t Timer1Value;

uint32_t PWMticks;
uint8_t CommState;
uint16_t ADCCommState;
uint8_t RampUpCommState;
uint8_t adcBackEMFFilter;
uint16_t PhaseAdvance = 0;
uint32_t PhaseAdvanceDegrees = PHASE_ADVANCE_DEGREES;
uint16_t BlankingCounter;
uint8_t LoopCnt_u8;
uint8_t BlankCnt_max_u8;

uint16_t V_M1;
uint16_t V_M2;
uint16_t V_M3;
uint16_t I_a;
uint16_t I_b;
uint16_t I_sum;
uint16_t V_pot;
uint16_t HallValue;		// Variable containing the Hall Value from PORTB
uint16_t RecNeutrVoltage;

uint8_t ComparatorOutputs;
uint8_t RotorPosition;
uint8_t RotorPosition_alt;
uint8_t RotorPosition_cnt;
uint8_t CompOld_u8;
uint8_t EnableCommutate_u8;

uint16_t DesiredPWMDutyCycle;
uint16_t CurrentPWMDutyCycle;
uint16_t ReferenceSpeed;

uint32_t Counter;
uint32_t PGxIOCONhelp;

void DelayNmSec(uint16_t Counter);
void PreCommutationState(void);
void OpenLoopController(void);
void StartMotor(void);
void StopMotor(void);


/*
 * 
 */
int main(int argc, char** argv)
{
    InitClock();
    SetupGPIOPorts();
    TIMER1_Initialize();
    TIMER1_InputClockSet();
    TIMER1_PeriodSet(TIMER1_PERIOD_COUNT);
    TIMER1_InterruptPrioritySet(5);
    TIMER1_InterruptFlagClear();
    TIMER1_InterruptEnable(); 
    TIMER1_ModuleStart();
#ifdef INTERNAL_OPAMP_CONFIG    
    OpampConfig();
#endif
    Init_ADC();
    InitPWMGenerators();
    DiagnosticsInit();
    BoardServiceInit();
    EnablePWMOutputsInverterA();
    PWMDutyCycleSet(LOOPTIME_TCY/2);
    SCCP1_setup_for_32Bit_Counter();
    SCCP2_setup_for_32Bit_Counter();
    
    while(1)
    {
        DiagnosticsStepMain();
         BoardService();

        if(IsPressed_Button1())
        {
            OnOff = 1;
            EnablePWMOutputsInverterA();
            LED1 = 1;
            StartMotor();
        }

        /****************** Motor is running *********************************/
        if(Flags.RunMotor) // while motor is running
        {
            /****************** Stop Motor *********************************/
            if(IsPressed_Button2())
            {
                OnOff = 0;
                StopMotor();
                DisablePWMOutputsInverterA();
                LED1 = 0;
            }
        }
    }
}

void __attribute__((__interrupt__)) _T1Interrupt()
{
    if(++Counter >= 5)
    {
        BoardServiceStepIsr();
        Counter = 0;
    }
//    LED2 ^= 1;
    _T1IF = 0;
}

void __attribute__((__interrupt__)) _PWM1Interrupt(void)
{
    /* Add your custom callback code here or implement
    the Callback in the application code, without the weak attribute */

    if(Flags.RunMotor)
    {
        //Ramp-up period to detect the rotor position
        if (Flags.RotorAlignment && Flags.RunMotor)
        {
            PG1DC = PG2DC = PG3DC = CurrentPWMDutyCycle;
            ++PWMticks;
        }
        //Check if the Ramp-up value is disabled, if so starts sensorless operation
        if (++PWMticks > MAX_PWM_TICKS)
        {
            PreCommutationState();
        }

        // Masking the BEMF signals according to the SECTOR in order to determine the ACTIVE BEMF signal
        // XOR operator helps to determine the direction of the upcoming zero-crossing slope
        BlankingCounter++;
        if(BlankingCounter > BLANKING_COUNT)
        {
            if((ComparatorOutputs^ADC_XOR[ADCCommState])& ADC_MASK[ADCCommState])
                adcBackEMFFilter|=0x01;

            //Majority detection filter	
            adcBackEMFFilter = ADC_BEMF_FILTER[adcBackEMFFilter];
            if (adcBackEMFFilter&0b00000001)
                PreCommutationState();
        }
    }
    HallValue = (0x0007 &((HALL_A_GetValue()<<2) + (HALL_B_GetValue()<<1) + HALL_C_GetValue()));
//    if(OnOff)
//    {
//        PG1IOCON &= 0xFFFF0000;
//        PG1IOCON += PWM_STATE1[CommutationSector[HallValue]];
//        PG2IOCON &= 0xFFFF0000;
//        PG2IOCON += PWM_STATE2[CommutationSector[HallValue]];
//        PG3IOCON &= 0xFFFF0000;
//        PG3IOCON += PWM_STATE3[CommutationSector[HallValue]];
//    }
//    else
//    {
//        DisablePWMOutputsInverterA();
//    }
    _PWM1IF = 0;
}

void __attribute__((__interrupt__))HAL_MC1ADCInterrupt(void)
{   
    I_a = ADCBUF_IA;
    I_b = ADCBUF_IB;
    V_pot = ReferenceSpeed = ADCBUF_POT * 5;
    V_M1 = ADCBUF_VM1;
    V_M2 = ADCBUF_VM2;
    V_M3 = ADCBUF_VM3;

    //Reconstrucs Voltage at the  Motor Neutral Point
    RecNeutrVoltage = (V_M1 + V_M2 + V_M3) / 3;

    /********************* ADC SAMPLING & BMEF signals comparison ****************/

    if (BlankingCounter > BlankCnt_max_u8)
    {        
        ComparatorOutputs = 0;						// Precondition all comparator bits as zeros
		if(V_M1 > RecNeutrVoltage)
			ComparatorOutputs += 1;					// Set bit 0 when Phase C is higher than Neutural
		if(V_M2 > RecNeutrVoltage)
			ComparatorOutputs += 2;					// Set bit 1 when Phase B is higher than Neutural
		if(V_M3 > RecNeutrVoltage)
			ComparatorOutputs += 4;					// Set bit 2 when Phase A is higher than Neutral
    }    

    DiagnosticsStepIsr();
    HAL_MC1ADCInterruptFlagClear;
}

void __attribute__((__interrupt__))_CCT1Interrupt(void)
{
    // Add your custom callback code here
    PG1IOCON &= 0xFFFF0000;
    PG1IOCON += PWM_STATE1[ADCCommState];
    PG2IOCON &= 0xFFFF0000;
    PG2IOCON += PWM_STATE2[ADCCommState];
    PG3IOCON &= 0xFFFF0000;
    PG3IOCON += PWM_STATE3[ADCCommState];

    BlankingCounter = 0;

    SCCP1_Stop(); // Stop TIMER1
    SCCP1_Timer_Clear();
    _CCT1IF = 0;
    
}

/******************************************************************************
 * Function:     PreCommutationState(void)
 *
 * Output:		None
 *
 * Overview:		This function measures the 60 and 30 electrical degrees
 *				using the TIMER2. The 60 electrical degrees is proportional
 *				to the elpased time between zero-crossing events.
 *				The zero-crossing events occur 30 electrical degrees in advace
 *				of the commutation point. Hence a delay proportional to the 30
 *				electrical degrees is added using the TIMER1
 *
 * Note:			None
 *******************************************************************************/
void PreCommutationState(void)
{
// Calculate the time proportional to the 60 electrical degrees
    SCCP2_Stop(); // Stop TIMER2
    Timer2Value_neu = SCCP2_Get_Timer_32Bit();
    Timer2Average = ((Timer2Average + Timer2Value_alt + Timer2Value_neu) / 3);
    Timer2Value_alt = Timer2Value_neu;
    SCCP2_Timer_Clear();
    SCCP2_Start(); // Start TIMER2
//Calculate the delay in TIMER1 counts proportional to the Phase Adv angle
    PhaseAdvance = ((Timer2Average * PhaseAdvanceDegrees) / 60);

// Calculate the time proportional to the 30 electrical degrees
// Load the TIMER1 with  the TIMER1 counts porportional to 30 deg	minus the PHASE ADV angle delay
    Timer1Value = (((Timer2Average) >> 1) - PhaseAdvance);
    if (Timer1Value > 1)
    {
        SCCP1_Set_Period_32Bit( Timer1Value );
    }
    else
    {
        Timer1Value = 1;
        SCCP1_Set_Period_32Bit( Timer1Value );
    }
    // Start TIMER1
    SCCP1_Timer_Clear();
    SCCP1_Start();

    //disabling rotor alignment & ramp-up sequence
    PWMticks = 0;
    RampUpCommState = 7;
    Flags.RotorAlignment = false;

//if Motor is runnining in sensorless mode and the PI button is ON on DMIC window
//then the PI controller is enabled if the PI button is OFF then motor runs in open loop
    if ((!Flags.RotorAlignment) && Flags.RunMotor)
    {
        OpenLoopController();
    }

    // Change The Six-Step Commutation Sector
    adcBackEMFFilter = 0;
    if (++ADCCommState > 6)
        ADCCommState = 1;
}

/******************************************************************************
 * Function:     OpenLoopController(void)
 *
 * Output:		None
 *
 * Overview:		When the PI button is OFF on the DMCI window
 *				the motor operates in open loop mode.
 *
 * Note:			None
 *******************************************************************************/
void OpenLoopController(void)
{
    //PWM duty cycle = pot value *3/2
    DesiredPWMDutyCycle = ReferenceSpeed;
    //Update the duty cycle according to the POT value, a POT follower is implemented here
    if (CurrentPWMDutyCycle != DesiredPWMDutyCycle)
    {
        if (CurrentPWMDutyCycle < DesiredPWMDutyCycle)
            CurrentPWMDutyCycle+=50;
        if (CurrentPWMDutyCycle > DesiredPWMDutyCycle)
            CurrentPWMDutyCycle-=50;
    }
    // Max and Min PWM duty cycle limits
    if (CurrentPWMDutyCycle < MIN_DUTY)
        CurrentPWMDutyCycle = MIN_DUTY;
    if (CurrentPWMDutyCycle > MAX_DUTY)
        CurrentPWMDutyCycle = MAX_DUTY;
    //Assigning new duty cycles to the PWM channels
    PG1DC = PG2DC = PG3DC = CurrentPWMDutyCycle;
//    PG2DC = CurrentPWMDutyCycle;
//    PG3DC = CurrentPWMDutyCycle;

}

/******************************************************************************
 * Function:     DelayNmSec(unsigned int N)
 *
 * Output:		None
 *
 * Overview:		Delay function used for push buttons debounce loop and for the
 *				motor start-up sequence
 *
 * Note:			None
 *******************************************************************************/
void DelayNmSec( uint16_t Counter )
{
uint16_t j;
    while (Counter--)
    {
        for (j = 0; j < 3000; j++){};
    }
}

void StartMotor(void)
{
    OnOff = true;
    SCCP2_Start();

    /*ROTOR ALIGNMENT SEQUENCE*/
    Flags.RotorAlignment = 1; // TURN ON rotor alignment sequence
    Flags.RunMotor = 1; // Indicating that motor is running
    CurrentPWMDutyCycle = STARTUP_DUTY; //Init PWM values
    DesiredPWMDutyCycle = STARTUP_DUTY; //Init PWM values
    PWMticks = 0; //Init Rotor aligment counter
    BlankCnt_max_u8 = BLANKING_COUNT;

    /************* Rotor alignment sequence and ramp-up sequence ************/
    for (RampUpCommState = 1; RampUpCommState < 7; RampUpCommState++)
    {
        while (PWMticks < MAX_PWM_TICKS && Flags.RotorAlignment)
        {
            PG1IOCON &= 0xFFFF0000;
            PG1IOCON += PWM_STATE1[RampUpCommState];
            PG2IOCON &= 0xFFFF0000;
            PG2IOCON += PWM_STATE2[RampUpCommState];
            PG3IOCON &= 0xFFFF0000;
            PG3IOCON += PWM_STATE3[RampUpCommState];
        }
        PWMticks = 0;
    }
    Flags.RotorAlignment = 0; // TURN OFF rotor alignment sequence
    PWMticks = MAX_PWM_TICKS + 1; // RAMP UP for breaking the motor IDLE state
    //DelayNmSec(RAM_UP_DELAY); // RAMP UP DELAY
}

void StopMotor(void)
{
    OnOff = false;
    Flags.RotorAlignment = 0; // turn on RAMP UP
    Flags.RunMotor = 0; // reset run flag
    CurrentPWMDutyCycle = 1; // Set PWM to the min value

    //Initi speed measurement variables & timer
    SCCP2_Stop();
    SCCP2_Timer_Clear();
    Timer2Value_alt = 0;
    Timer2Average = 0;
    SCCP1_Stop(); // Stop TIMER1
    SCCP1_Timer_Clear();
    PG1DC = PG2DC = PG3DC = 0;
    DisablePWMOutputsInverterA();
}

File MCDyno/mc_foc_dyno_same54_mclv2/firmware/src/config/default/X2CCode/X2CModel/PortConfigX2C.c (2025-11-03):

/* This file is part of X2C. http://www.mechatronic-simulation.org/                                                   */

#include "X2C.h"
#include "PortConfigX2C.h"
#include "definitions.h"

#include "../../../../userparams.h"
#include "can1_Lib.h"

uint16_t rotor_elec_count;
uint16_t rotor_mech_count;
uint16_t rotor_speed_count;

int16_t pos_count_diff = 0;
float speed_elec = 0.0;

static unsigned char S3_Value;
static unsigned char S3_Value_old = 1;
static unsigned char DebounceCnt;
static unsigned char edge=0;

extern int16_t  adc_0_offset;
extern int16_t  adc_1_offset;
extern uint16_t phaseA_current_raw;
extern uint16_t phaseB_current_raw;
extern uint16_t dcbus_raw;
extern uint16_t pot_raw;
extern int16_t CpuLoad;

uint32_t  duty_A;
uint32_t  duty_B;
uint32_t  duty_C;
bool adcCalibrated = false;

//Structure containing variables used in position and speed calculation
typedef struct
{
  int16_t prev_position_count;
  int16_t present_position_count;
  uint16_t QDECcnt;
  uint16_t QDECcntZ;
  uint16_t posCntElec;
  uint16_t posCntMech;
  uint16_t posCompensation;
  uint32_t posCntTmp;
  
}MCAPP_POSITION_CALC;

MCAPP_POSITION_CALC  gPositionCalc;


extern uint16_t TimerEncoderFilter;
extern uint16_t slow_loop_count;
void Reset_Position(void);


void readInports(void)
{
	/* TODO add linkage hardware-inputs -> X2C inports here 
     * Pass the peripheral values to model Inports
     * if (PORTA & 1) { 
     *    x2cModel.inports.bInport = INT16_MAX;
     * }else {
     *    x2cModel.inports.bInport = 0;
     * }
	 */
    
    x2cModel.inports.bI_a = (phaseA_current_raw-adc_0_offset)<<4;
    x2cModel.inports.bI_b = (phaseB_current_raw-adc_1_offset)<<4;
    x2cModel.inports.bV_POT = (pot_raw)<<3;  // pot value between 0 and 1 (=INT16_MAX) 
    x2cModel.inports.bV_DCLINK = dcbus_raw;// EL01 to be fixed (dcbus_raw * 48) / 4095;
   
    /* Button latch and debounce */
    
    if(SW2_Get()==0) x2cModel.inports.bS2 = 0;
    else  x2cModel.inports.bS2 = INT16_MAX;
    
    S3_Value = SW3_Get();
    // x2cModel.inports.bS2 =  S3_Value;    
    if(edge==0)
    {
        if (S3_Value != S3_Value_old) 
        {
            S3_Value_old = S3_Value;
            if(S3_Value)
            {
                DebounceCnt = 0;
                edge = 1;
            }
        }
    }
    else
    {
        DebounceCnt++;
        if(DebounceCnt >= 10)
        {           
            if(x2cModel.inports.bS3==0)
            {
                x2cModel.inports.bS3 = INT16_MAX;
            }
            else
            {
                x2cModel.inports.bS3 = 0;
            }
            
            DebounceCnt = 0;
            edge=0;
        }    
    }
    if (*x2cModel.outports.bHOME_INIT == 0) { // read the encode after the HOME_INIT sequence 
        // Get Rotor Position from QDEC     
        gPositionCalc.QDECcnt = PDEC_QDECPositionGet();
        if((gPositionCalc.QDECcnt>QDEC_UPPER_THRESHOLD) && (gPositionCalc.QDECcntZ<QDEC_LOWER_THRESHOLD))
        {
            gPositionCalc.posCompensation += QDEC_UNDERFLOW;
        } 
        else if((gPositionCalc.QDECcntZ>QDEC_UPPER_THRESHOLD) && (gPositionCalc.QDECcnt<QDEC_LOWER_THRESHOLD))
        {
            gPositionCalc.posCompensation += QDEC_OVERFLOW;           
        } 
        gPositionCalc.posCompensation = gPositionCalc.posCompensation % ENCODER_PULSES_PER_ELEC_REV;
        gPositionCalc.posCntTmp = gPositionCalc.QDECcnt + gPositionCalc.posCompensation;
        gPositionCalc.posCntElec = (gPositionCalc.posCntTmp % ENCODER_PULSES_PER_ELEC_REV) * QEI_FACT_ELEC;
        rotor_elec_count = gPositionCalc.posCntElec;
        gPositionCalc.posCntMech = (gPositionCalc.posCntTmp % ENCODER_PULSES_PER_MECH_REV) * QEI_FACT_MECH;
        rotor_mech_count = gPositionCalc.posCntMech; 
        gPositionCalc.QDECcntZ = gPositionCalc.QDECcnt;    
        // Speed Calculation from Encoder
        if (slow_loop_count >= SPEED_SAMPLE_FREQ)
        {
            slow_loop_count = 0;            
            gPositionCalc.present_position_count = (int16_t)(PDEC_QDECPositionGet());
            pos_count_diff = gPositionCalc.present_position_count - gPositionCalc.prev_position_count;
            speed_elec = (float)pos_count_diff * ((60.0 * (float)(PWM_FREQ / SPEED_SAMPLE_FREQ)*(float)INT16_MAX) / ((float)MAX_SPEED*(float)ENCODER_PULSES_PER_MECH_REV)); 
            rotor_speed_count = (int16_t)speed_elec;
            gPositionCalc.prev_position_count = gPositionCalc.present_position_count;
        }
    }
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

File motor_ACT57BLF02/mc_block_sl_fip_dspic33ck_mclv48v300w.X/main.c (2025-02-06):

/**
  Generated main.c file from MPLAB Code Configurator

  @Company
    Microchip Technology Inc.

  @File Name
    main.c

  @Summary
    This is the generated main.c using PIC24 / dsPIC33 / PIC32MM MCUs.

  @Description
    This source file provides main entry point for system initialization and application code development.
    Generation Information :
        Product Revision  :  PIC24 / dsPIC33 / PIC32MM MCUs - 1.170.0
        Device            :  dsPIC33CK256MP508
    The generated drivers are tested against the following:
        Compiler          :  XC16 v1.61
        MPLAB 	          :  MPLAB X v5.45
*/

/*
    (c) 2020 Microchip Technology Inc. and its subsidiaries. You may use this
    software and any derivatives exclusively with Microchip products.

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
    IN NO EVENT WILL MICROCHIP BE LIABLE FOR ANY INDIRECT, SPECIAL, PUNITIVE,
    INCIDENTAL OR CONSEQUENTIAL LOSS, DAMAGE, COST OR EXPENSE OF ANY KIND
    WHATSOEVER RELATED TO THE SOFTWARE, HOWEVER CAUSED, EVEN IF MICROCHIP HAS
    BEEN ADVISED OF THE POSSIBILITY OR THE DAMAGES ARE FORESEEABLE. TO THE
    FULLEST EXTENT ALLOWED BY LAW, MICROCHIP'S TOTAL LIABILITY ON ALL CLAIMS IN
    ANY WAY RELATED TO THIS SOFTWARE WILL NOT EXCEED THE AMOUNT OF FEES, IF ANY,
    THAT YOU HAVE PAID DIRECTLY TO MICROCHIP FOR THIS SOFTWARE.

    MICROCHIP PROVIDES THIS SOFTWARE CONDITIONALLY UPON YOUR ACCEPTANCE OF THESE
    TERMS.
*/

/**
  Section: Included Files
*/
#include "mcc_generated_files/system.h"
#include "mcc_generated_files/X2Cscope/X2CscopeComm.h"
#include "mcc_generated_files/X2Cscope/X2Cscope.h"
#include "mcc_generated_files/adc1.h"
#include "mcc_generated_files/sccp1_tmr.h"
#include "mcc_generated_files/sccp3_tmr.h"
#include "mcc_generated_files/pin_manager.h"
#include "mcc_generated_files/pwm.h"

const uint16_t PWM_STATE1[8] = {0x3000, 0x3400, 0x3000, 0x1000, 0x1000, 0x3000, 0x3400, 0x3000};
const uint16_t PWM_STATE2[8] = {0x3000, 0x3000, 0x3400, 0x3400, 0x3000, 0x1000, 0x1000, 0x3000};
const uint16_t PWM_STATE3[8] = {0x3000, 0x1000, 0x1000, 0x3000, 0x3400, 0x3400, 0x3000, 0x3000};
uint16_t commutation_sector[8] = {0, 1, 2, 3, 4, 5, 6, 0};

/* AND & OR operators for masking the active BEMF signal */
const unsigned int ADC_MASK[8] = {0x0000, 0x0002, 0x0001, 0x0004, 0x0002, 0x0001, 0x0004, 0x0000};
const unsigned int ADC_XOR[8] = {0x0000, 0x0000, 0xFFFF, 0x0000, 0xFFFF, 0x0000, 0xFFFF, 0x0000};

/* BEMF Majority Function Filter values */
const unsigned char ADC_BEMF_FILTER[64] = {
    0x00, 0x02, 0x04, 0x06, 0x08, 0x0A, 0x0C, 0x0E, 0x10, 0x12, 0x14, 0x16, 0x18, 0x1A, 0x1C, 0x1E,
    0x20, 0x22, 0x24, 0x26, 0x28, 0x2A, 0x2C, 0x2E, 0x01, 0x01, 0x01, 0x36, 0x01, 0x3A, 0x3C, 0x3E,
    0x00, 0x02, 0x04, 0x06, 0x08, 0x0A, 0x0C, 0x0E, 0x01, 0x01, 0x01, 0x16, 0x01, 0x1A, 0x1C, 0x1E,
    0x01, 0x01, 0x01, 0x26, 0x01, 0x2A, 0x2C, 0x2E, 0x01, 0x01, 0x01, 0x36, 0x01, 0x3A, 0x3C, 0x3E
};


#define MAX_PWM_TICKS           200     // To detect initial rotor position
#define MAX_STARTUP_CNT         10      // Number of Turns for startup
#define RAM_UP_DELAY            0    	// Delay for the ramp up sequence, expressed in millisecond
#define ONE_MS                  391
#define MIN_PERIOD              5
#define MAX_PERIOD              50
#define MIN_DUTY                200
#define STARTUP_DUTY            800
#define MAX_DUTY                4999
#define PHASE_ADVANCE_DEGREES   12      // Phase advance angles to get the best motor performance
#define BLANKING_COUNT          3		// Blanking counts after section commuting for zero-crossing detection
#define ROTOR_POSITION_FLT      5

#define DIRECTION_LED_HIGH      600
#define DIRECTION_LED_LOW       100

/*Application Flags to indicate the motor status*/
struct
{
    unsigned running : 1;
    unsigned alignment : 1;
    unsigned unused : 14;
} Motor;

uint16_t duty_cycle = MIN_DUTY;

uint16_t commutation_idx = 0;
uint16_t timer_60deg_new;
uint16_t timer_60deg_old;
uint16_t timer_60deg_average;
uint16_t timer_30deg_value;

uint16_t PWMticks;
uint16_t adc_comm_state;
uint8_t rampUp_comm_state;
uint8_t adc_BEMF_filter;
uint16_t phase_advance_value = 0;
uint16_t phase_advance_degrees = PHASE_ADVANCE_DEGREES;
uint16_t blanking_counter;
uint8_t blank_max_count;

uint16_t V_M1;
uint16_t V_M2;
uint16_t V_M3;
uint16_t I_a;
uint16_t I_b;
uint16_t I_sum;
uint16_t V_pot;
uint16_t neutral_voltage;

uint8_t comparator_output;

uint16_t target_PWM_dutyCycle;
uint16_t current_PWM_dutyCycle;
uint16_t ref_speed;

uint16_t millis = 0;
uint8_t direction = 0;
uint8_t motor_active = 0;
uint16_t led_counter = 0;

void pre_commutation_state(void);
void open_loop_controller(void);
void delay_millis(uint16_t counter);
void start_stop_motor(void);
void start_motor(void);
void stop_motor(void);
void change_direction(void);

/*
                         Main application
 */
int main(void)
{
    // initialize the device
    SYSTEM_Initialize();
    SW1_SetInterruptHandler(change_direction);
    SW2_SetInterruptHandler(start_stop_motor);
    
    while(1)
    {
        X2CScope_Communicate();
    }
    return 1; 
}

void start_stop_motor(void)
{
    motor_active ^= 1;
    if(motor_active)
    {
        start_motor();
    }
    else
    {
        stop_motor();
    }
}

void start_motor(void)
{
    if(Motor.running) return;
    LED1_SetHigh();
    
    // Start 60 degrees timer counter
    SCCP3_TMR_Start();

    /* ROTOR ALIGNMENT SEQUENCE */
    Motor.alignment = 1; // TURN ON rotor alignment sequence
    Motor.running = 1; // Indicating that motor is running
    current_PWM_dutyCycle = STARTUP_DUTY; // Initiate PWM values
    target_PWM_dutyCycle = STARTUP_DUTY; // Initiate PWM values
    PG1DC = PG2DC = PG3DC = current_PWM_dutyCycle;
    PWMticks = 0; // Initiate Rotor alignment counter
    blank_max_count = BLANKING_COUNT;

    /************* Rotor alignment sequence and ramp-up sequence ************/
    for (rampUp_comm_state = 1; rampUp_comm_state < 7; rampUp_comm_state++)
    {
        while (PWMticks < MAX_PWM_TICKS && Motor.alignment)
        {
            commutation_idx = commutation_sector[rampUp_comm_state];
            PG1IOCONL = PWM_STATE1[commutation_idx];
            PG2IOCONL = PWM_STATE2[commutation_idx];
            PG3IOCONL = PWM_STATE3[commutation_idx];
        }
        PWMticks = 0;
        delay_millis(RAM_UP_DELAY); // RAMP UP DELAY   
    }
    Motor.alignment = 0; // TURN OFF rotor alignment sequence
    PWMticks = MAX_PWM_TICKS + 1; // RAMP UP for breaking the motor IDLE state
}
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

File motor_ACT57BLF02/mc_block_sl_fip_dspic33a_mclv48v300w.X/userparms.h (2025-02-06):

#ifndef _USER_HEADER
#define _USER_HEADER

#include <math.h>

#define MAX_CURRENT                 (float)(22.0)
#define ADC_CURRENT_SCALE           (float)(MAX_CURRENT/(float)32768)
#define ADC_CURRENT_SCALE_INVERSE   (float)((float)32768/ MAX_CURRENT)
#define DC_BUS_VOLTAGE              (float)24
#define MOTOR_PER_PHASE_RESISTANCE                          ((float)2.833)
#define MOTOR_PER_PHASE_INDUCTANCE                          ((float)((0.00243)))
#define MOTOR_BACK_EMF_CONSTANT_Vpeak_Line_Line_KRPM_MECH   (float)7.5678
#define NOPOLESPAIRS                    5

#undef OPEN_LOOP_FUNCTIONING
#undef TORQUE_MODE
#define INTERNAL_OPAMP_CONFIG
#undef SINGLE_SHUNT

#define SINGLE_ELEC_ROT_RADS_PER_SEC    (float)(2.0*M_PI)
#define MAX_DUTY                        19999 // For 5KHz PWM frequency on dsPIC33CK device
#define MIN_DUTY                        2000
#define SQRT_3                          (float)1.732
#define LOOPTIME_SEC                    (float)0.00005           // PWM Period - 200 uSec, 5Khz PWM
#define DEADTIME                        (float)0.0000005
#define EFFECTIVE_MAX_DUTY              (float)((LOOPTIME_SEC - DEADTIME)/LOOPTIME_SEC)
#define LOCK_TIME_IN_SEC                1
#define LOCK_COUNT_FOR_LOCK_TIME        (unsigned int)((float)LOCK_TIME_IN_SEC/(float)LOOPTIME_SEC)
#define LOCK_TIME_IN_SEC                1
#define LOCK_COUNT_FOR_LOCK_TIME        (unsigned int)((float)LOCK_TIME_IN_SEC/(float)LOOPTIME_SEC)
#define END_SPEED_RPM                   500 // Value in RPM


#define END_SPEED_RPS               ((float)END_SPEED_RPM/60)
// In 1 second, the motor maked "END_SPEED_RPS" mechanical rotations
#define RAMP_TIME_IN_SEC                3
#define END_SPEED_RADS_SEC_SEC_MECH (float)(END_SPEED_RPS * SINGLE_ELEC_ROT_RADS_PER_SEC)
#define END_SPEED_RADS_SEC_SEC_ELEC (float)(END_SPEED_RADS_SEC_SEC_MECH * NOPOLESPAIRS)
#define END_SPEED_RADS_SEC_SEC_ELEC_IN_LOOPTIME (float)(END_SPEED_RADS_SEC_SEC_ELEC * LOOPTIME_SEC)
//#define OPENLOOP_RAMPSPEED_INCREASERATE     (float)(END_SPEED_RADS_SEC_SEC_ELEC_IN_LOOPTIME/(RAMP_TIME_IN_SEC/LOOPTIME_SEC))
#define OPENLOOP_RAMPSPEED_INCREASERATE     (float)(END_SPEED_RADS_SEC_SEC_ELEC/(RAMP_TIME_IN_SEC/LOOPTIME_SEC))
/* end speed conveted to fit the startup ramp */
#define Q_CURRENT_REF_OPENLOOP           0.1
/* Nominal speed of the motor in RPM */
#define NOMINAL_SPEED_RPM                                (float)2000 // Value in RPM
#define NOMINAL_SPEED_RAD_PER_SEC_ELEC                   (float)(((NOMINAL_SPEED_RPM/60)*2*M_PI)*5) // Value in RPM

   
#define DC_BUS_VOLTAGE_DUE_TO_SVM     (float)((DC_BUS_VOLTAGE * EFFECTIVE_MAX_DUTY)/SQRT_3)

#define MOTOR_BACK_EMF_CONSTANT_Vpeak_PHASE_RPM_MECH                    (float)((MOTOR_BACK_EMF_CONSTANT_Vpeak_Line_Line_KRPM_MECH/1.732)/1000)
#define MOTOR_BACK_EMF_CONSTANT_Vpeak_PHASE_RPS_MECH                    (float)(MOTOR_BACK_EMF_CONSTANT_Vpeak_PHASE_RPM_MECH * 60)
#define MOTOR_BACK_EMF_CONSTANT_Vpeak_PHASE_RAD_PER_SEC_MECH        (float)(MOTOR_BACK_EMF_CONSTANT_Vpeak_PHASE_RPS_MECH/(2*M_PI))
#define MOTOR_BACK_EMF_CONSTANT_Vpeak_PHASE_RAD_PER_SEC_ELEC        (float)(MOTOR_BACK_EMF_CONSTANT_Vpeak_PHASE_RAD_PER_SEC_MECH/NOPOLESPAIRS)

/* PI controllers tuning values - */
//******** D Control Loop Coefficients *******
#define     D_CURRCNTR_PTERM           5.61/2//(0.05/MAX_CURRENT)
#define     D_CURRCNTR_ITERM           0.35/2//(0.003 /MAX_CURRENT)
#define     D_CURRCNTR_CTERM           1;//(0.999/MAX_CURRENT)
#define     D_CURRCNTR_OUTMAX          DC_BUS_VOLTAGE_DUE_TO_SVM

//******** Q Control Loop Coefficients *******
#define     Q_CURRCNTR_PTERM           5.61/2//(0.05/MAX_CURRENT)
#define     Q_CURRCNTR_ITERM           0.35/2//(0.003 /MAX_CURRENT)
#define     Q_CURRCNTR_CTERM           1;//(0.999/MAX_CURRENT)
#define     Q_CURRCNTR_OUTMAX          DC_BUS_VOLTAGE_DUE_TO_SVM

//*** Velocity Control Loop Coefficients *****
#define     SPEEDCNTR_PTERM        0.003367/2//(0.07 * 4 * (M_PI/30))
#define     SPEEDCNTR_ITERM        0.00000084/2//(0.001 * (M_PI/30))//0.005
#define     SPEEDCNTR_CTERM        1;//0.005//(0.005 * (30/M_PI))//0.005
#define     SPEEDCNTR_OUTMAX       2.0  // Max current allowed is 2.0 Amps
/****************************************************************************/
/****************************************************************************/
/****************************************************************************/
/****************************************************************************/
#define KFILTER_ESDQ                        (float)((float)(4327*2)/(float)32767)
#define KFILTER_VELESTIM                    (float)((float)(2801*2)/(float)32767)
#define INITOFFSET_TRANS_OPEN_CLSD          (float)((float)0/(float)32767)


#define FW_SPEED_RPM                        (float)3500
#define FW_SPEED_RAD_PER_SEC_ELEC           (float)(((FW_SPEED_RPM/60)*2*M_PI)*5)
#define SPEED_COMMAND_RAMP_UP_TIME          (float)25.0 // seconds
#define MAX_FW_NEGATIVE_ID_REF              (float)(-2)

#endif

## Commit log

2025-02-06 ck and a AN1160 added
    [ScopeConfig.cfg]
2025-03-20 motor spinning with ~2300rpm
2025-11-03 directory changes
    [EBM_EC63.20_unified_V1_00.scad, EBM_EC63.20_unified_V1_00.stl, Elra_IPM110_HV_V1_00.scad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]
2026-01-08 download button in website for igat hex file
2026-01-08 Track IGaT HEX in repo
2026-01-08 Publish motor DIM HEX and docs site
2026-01-08 Space motor DIM download buttons
2026-01-12 created 3d model folder
    [EBM_EC63.20_unified_V1_00.scad, EBM_EC63.20_unified_V1_00.stl, Elra_IPM110_HV_V1_00.scad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]
2026-01-12 addded more 3d Models
    [ACT-Flat-Adapter.stl, ACT42BLF_blue_wedge_V1_00.scad, ACT42BLF_blue_wedge_V1_00.stl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]
2026-01-13 mount motor update step 1
2026-05-14 Update programming instructions for PKOB4
    MCLV-48V-300W has on-board PKOB4 programmer - no external
    programmer needed. Added note for MCLV-2 users who need
    an external programmer.
